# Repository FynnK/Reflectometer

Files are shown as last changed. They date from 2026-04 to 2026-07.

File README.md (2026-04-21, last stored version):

---
tags:
  - electronics
  - hardware-design
  - water-sensor
  - obsidian-skills
status: design-complete
---

---
tags:
  - electronics
  - hardware-design
  - water-sensor
status: design-complete
---

# Multi-LED Spectral Water Quality Sensor

> [!info] Project Overview
> A 24-bit isolated sensing system using pulsed 100mA current sources to measure liquid reflection across three wavelengths (Red, Green, Blue).

## System Architecture

```mermaid
graph TD
    %% -- Non-Isolated Side --
    subgraph NonIsolated ["Power and Control (Digital)"]
        USB[MicroUSB Connector]
        ESP32[ESP32-C3 MCU]
        C_IN[10uF CL21A106]
    end

    %% -- Isolation Barrier --
    subgraph Moat ["Isolation Barrier"]
        ISO1[ISO6742 SPI]
        ISO2[ISO6742 Control]
        ISO3[ISO6742 Extra]
        TRACO[TEA 1-0505 DC/DC]
    end

    %% -- Isolated Side --
    subgraph Isolated ["Isolated Analog Island"]
        %% Power Path
        L47[47uH WE Inductor]
        C_BULK[10uF Filtered]
        TPS[TPS60403 Inverter]
        
        %% Control Signals
        PWM[PWM Filter]
        GATE_SEL[BS170 Selector Gates]
        
        %% Signal Chain
        PD[BPW34S Photodiode]
        TIA[TLV172 TIA]
        ADC[ADS131M02]
        
        %% LED Current Path
        LEDS[RGB LED Array]
        SINK[BS170 Regulator]
        RSENSE[10 ohm Sense Resistor]
    end

    %% Cross-Barrier Links
    USB --> C_IN
    C_IN --> ESP32
    C_IN --> TRACO
    ESP32 --> ISO1
    ESP32 --> ISO2
    
    %% Isolated Routing
    TRACO --> L47
    L47 --> C_BULK
    C_BULK --> TPS
    C_BULK --> LEDS
    
    ISO1 --> ADC
    ISO2 --> PWM
    ISO2 --> GATE_SEL
    
    LEDS --> GATE_SEL
    GATE_SEL --> SINK
    SINK --> RSENSE
    RSENSE --> ADC
    
    PD --> TIA
    TIA --> ADC
````

## Hardware Component Logic

### 1. Power & Noise Suppression

- **Isolated DC/DC:** Uses the [[TEA 1-0505]] to break ground loops.
    
- **The Filter:** A Pi-filter using the **47uH Würth Inductor** and **Ferrite Beads** to scrub switching noise.
    
- **Negative Rail:** The **TPS60403** provides a -5V rail for the **TLV172** to allow the TIA to swing to absolute zero.

### 2. The 100mA Pulsed Source

> [!tip] Ratiometric Measurement
> 
> By routing the voltage from the **10 ohm Sense Resistor** back to ADC Channel 2, we calculate the ratio of reflected light to actual LED current. This cancels out power supply ripples.

- **Regulation:** TLV172 + BS170 (Main Sink).
    
- **Switching:** 3x BS170 (Color Selectors).

## Component List & Budget

|**Component**|**Function**|**Cost**|
|---|---|---|
|[[ADS131M02]]|24-bit ADC|€4.41|
|[[ISO6742]] (x3)|Digital Isolation|€7.68|
|[[TLV172]] (x2)|TIA & Current Source|€2.96|
|[[TEA 1-0505]]|Isolated Power|€1.65|

**Total Estimated BOM:** €24.64 ^total-cost

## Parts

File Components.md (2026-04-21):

| **Category** | **Description** | **Component** | **Value** | **KiCAD Footprint** | **Digikey** | **Price/pcs** |
| --- | --- | --- | --- | --- | --- | --- |
| **Passive** | Capacitor 0805 | CC0805JRNPO9BN470 | 47pF 16V | C0805_2012Metric_Pad1.18x1.45mm_HandSolder  | 311-1107-2-ND | 0,08 € |
| **Passive** | Capacitor 0805 | C0805C103K5RACTU | 10nF 16V | C0805_2012Metric_Pad1.18x1.45mm_HandSolder  | 399-C0805C103K5RACTUTR-ND | 0,07 € |
| **Passive** | Capacitor 0805 | C0805C104K5RACTU | 100nF 16V | C0805_2012Metric_Pad1.18x1.45mm_HandSolder  | 399-C0805C104K5RACTUTR-ND | 0,01 € |
| **Passive** | Capacitor 0805 | C0805C224K5RACTU | 220nF 16V | C0805_2012Metric_Pad1.18x1.45mm_HandSolder  | 399-C0805C224K5RACTUTR-ND | 0,07 € |
| **Passive** | Capacitor 0805 | CL21B105KAFNNNG | 1uF 16V | C0805_2012Metric_Pad1.18x1.45mm_HandSolder  | 1276-6469-2-ND | 0,08 € |
| **Passive** | Capacitor 0805 | CL21A106KOQNNNE | 10uF 16V | C0805_2012Metric_Pad1.18x1.45mm_HandSolder  | 1276-1096-2-ND | 0,08 € |
| **Passive** | Capacitor Electrolyte | 865080343009 | 100uF | CP_Elec_6.3x5.7 | 732-8419 | 0,28 € |
| **Passive** | Resistor 0805 | - | 1Ohm-10Meg | R0805_2012MetricPad1.20x1.40mm_HandSolder | x- | - € |
| **Passive** | Inductor | WE 7447462022 | 2.2uH | L_Radial_D7.0mm_P3.00mm | 732-2566-ND | 0,87 € |
| **Passive** | Inductor | WE 7447462047 | 4.7uH | L_Radial_D7.0mm_P3.00mm | 732-2568-ND | 0,87 € |
| **Passive** | Inductor | WE 744732470 | 47uH | L_Radial_D9.5mm_P5.00mm_Fastron | 732-3748-ND | 1,27 € |
| **Passive** | Inductor / Ferrite | BLM18AG601SN1D | - | L_0603_1608Metric_Pad1.05x0.95mm_HandSolder | 490-1014 | 0,10 € |
| **Connectors** | Stiftleiste 2,54mm | Pinzahl beliebig | Conn_01x10Pin etc. | PinHeader_1x10_P2.54_Vertical etc. | 732-5334-ND | - |
| **Connectors** | Sockelleiste 2,54mm | 801-87-050-10-001101 | Conn_01x10Pin etc. | PinHeader_1x10_P2.54_Vertical etc. | 1212-1218-ND | - |
| **Connectors** | Jumper 2,54mm | QPC02SXGN-RC | - | PinHeader_1x2_P2.54_Vertical | S9337-ND | - |
| **Connectors** | MicroUSB Connector | Amphenol 10103594 | - | KiCADComponent | 609-4050 | 0,80 € |
| **Connectors** | 4*AA Battery Holder | Keystone 2478 | 2 Pins | - | 36-2478-ND | 1,94 € |
| **Active** | Instrumentation Amp | INA128 SOIC8 | - | KiCADComponent | 296-26057 | 9,28 € |
| **Active** | Operational Amp | TLV172 SOIC8 | - | KiCADComponent | 296-47279 | 1,48 € |
| **Active** | Operational Amp | LM321 SOT23-5 | - | KiCADComponent | LM321SN3T1GOSTR-ND | 0,10 € |
| **Active** | NPN Transistor | BC547C TO-92 | - | KiCADComponent | 4878-BC547CCT-ND | 0,14 € |
| **Active** | PNP Transistor | BC557C TO-92 | - | KiCADComponent | 4878-BC557 | 0,14 € |
| **Active** | N-CH MOSFET | BS170 SOT-23-3 | - | KiCADComponent | 4518-BS170FTATR-ND | 0,25 € |
| **Active** | P-CH MOSFET | BSS84 SOT-23-3 | - | KiCADComponent | BSS84TR-ND | 0,34 € |
| **Active** | LED blue | 150120BS75000 | - | LED_1206_3216Metric_HandSolder | 32-4989-2-ND | 0,23 € |
| **Active** | LED green | 150120GS75000 | - | LED_1206_3216Metric_HandSolder | 732-4990-2-ND | 0,23 € |
| **Active** | LED superred | 150120SS75000 | - | LED_1206_3216Metric_HandSolder | 732-4992-2-ND | 0,23 € |
| **Active** | Photodiode | Vishay BPW34S SMD | - | KiCADComponent | 475-BPW34S-ZTR-ND | 1,09 € |
| **Active** | Analog Multiplexer | ADG734 | - | KiCADComponent | ADG734BRUZ-REELTR-ND | 4,70 € |
| **Active** | USB Interface | MCP2221AT-I/SL | SOIC14 | KiCADComponent | 150-MCP2221AT-I/SLTR-ND | 2,53 € |
| **Active** | Digital Isolator | ISO6742 | SOIC16 | KiCADComponent | 296-ISO6742FDWRTR-ND | 2,56 € |
| **Active** | DCDC Converter | TEA 1-0505 | - | KiCADComponent | 951-TEA1-0505-ND | 1,65 € |
| **Active** | LDO positive | LM317_SOT-223 | configurable | KiCADComponent | 296-12602-2-ND | 0,63 € |
| **Active** | LDO negative | LM337_TO252 | configurable | KiCADComponent | 296-21578-2-ND | 1,00 € |
| **Active** | Voltage Inverter | TPS60403QDBVRQ1 | Charge Pump | KiCADComponent | 296-18036-2-ND | 1,16 € |
| **Active** | ADC 24 Bit | ADS131M02 | ADS131M04 | Schematic and Layout | 296-ADS131M02 | 4,41 € |

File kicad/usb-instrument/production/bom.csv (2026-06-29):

Designator | Footprint | Quantity | Value | LCSC Part #
C1, C19, C2 | 0805 | 3 | 10n
C10, C13, C17, C18, C4, C9 | 0805 | 6 | 100n
C11, C14, C16, C21 | 0805 | 4 | 10u
C12, C20, C25 | 0805 | 3 | 220n
C15 | CP_Elec_6.3x5.7 | 1 | 100u
C22, C23, C24, C5 | 0805 | 4 | 1u
C3 | 0805 | 1 | 47p (optional)
D4 | Osram_BPW34S-SMD | 1 | BPW34-SMD
D5, D6, D7 | 1206 | 3 | LED
FB1 | 0603 | 1 | FerriteBead
J1 | USB_Micro-B_Amphenol_10103594-0001LF_Horizontal | 1 | USB_B_Micro
J2 | USB_C_Receptacle_G-Switch_GT-USB-7010ASV | 1 | USB_C_Receptacle_USB2.0_14P
Q5, Q7, Q8 | SOT-23-3 | 3 | BS170
Q6 | SOT-23 | 1 | BSS84
R1, R2, R28, R3, R4 | 0805 | 5 | 1k
R11, R12, R26, R27, R8 | 0805 | 5 | 10k
R13 | 0805 | 1 | 18k
R14 | 0805 | 1 | 220
R15 | 0805 | 1 | 360
R18, R19 | 0805 | 2 | 4.7k
R29, R30, R34, R36 | 0805 | 4 | 100
R31, R35, R37 | 0805 | 3 | 47k
R32 | 0805 | 1 | 33
R33 | 0805 | 1 | 1
R5, R6 | 0805 | 2 | 5k1
R7 | 0805 | 1 | 22
TP1 | TestPoint_Pad_D2.5mm | 1 | MCP_RX
TP17 | TestPoint_Pad_D2.5mm | 1 | TestPoint
TP2 | TestPoint_Pad_D2.5mm | 1 | MCP_TX
U1 | XIAO-ESP32-C3-DIP-SMD | 1 | XIAO-ESP32-C3-DIP
U12, U13 | SOT-23-5 | 2 | LM321
U3 | SOT-223-3_TabPin2 | 1 | LM317_SOT-223
U4 | SOIC-16W_7.5x10.3mm_P1.27mm | 1 | ISO6742
U5 | SOIC-14_3.9x8.7mm_P1.27mm | 1 | MCP2221AxSL
U6 | TSSOP20_PW_TEX | 1 | ADS131M02IPWR
U8 | Converter_DCDC_TRACO_TEA1-xxxx_THT | 1 | TEA 1-0505
U9 | SOIC-8-1EP_3.9x4.9mm_P1.27mm_EP2.514x3.2mm | 1 | TLV172IDCK
Y1 | Crystal_SMD_7050-4Pin_7.0x5.0mm | 1 | XO32

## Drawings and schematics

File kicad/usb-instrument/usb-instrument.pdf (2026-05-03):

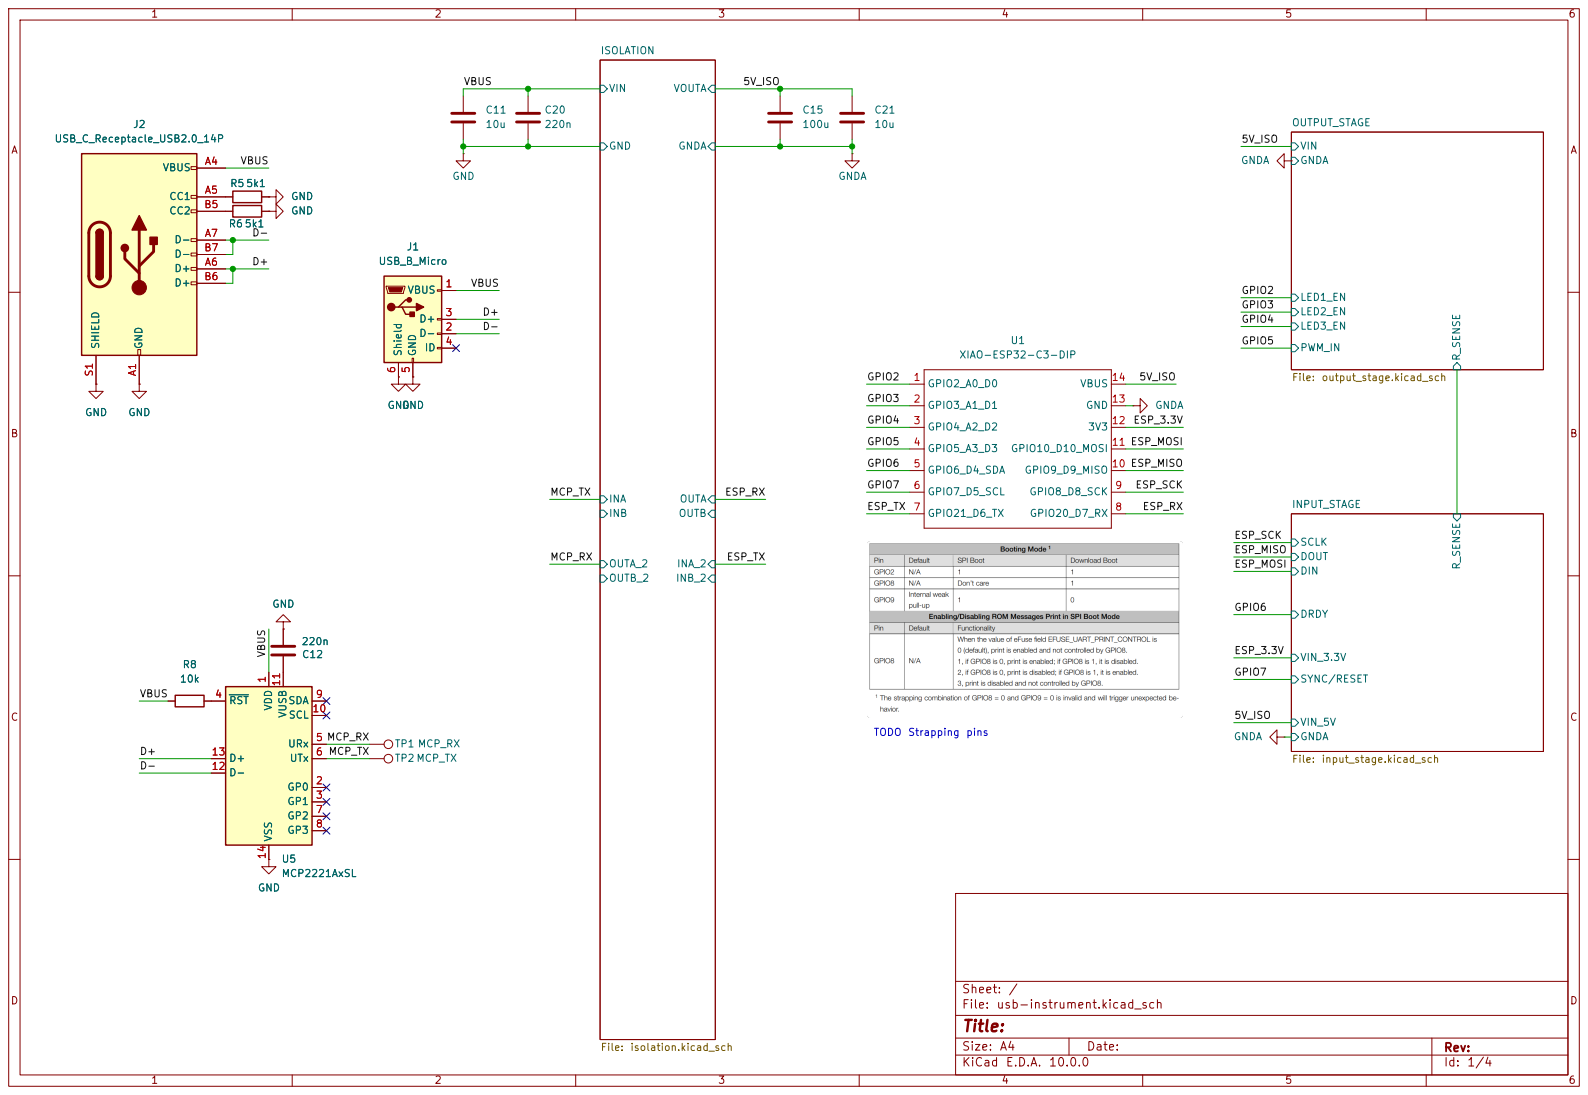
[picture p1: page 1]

TODO Strapping pins GND

Size: A4 | Rev:
KiCad E.D.A. 10.0.0 | Id: 1/4

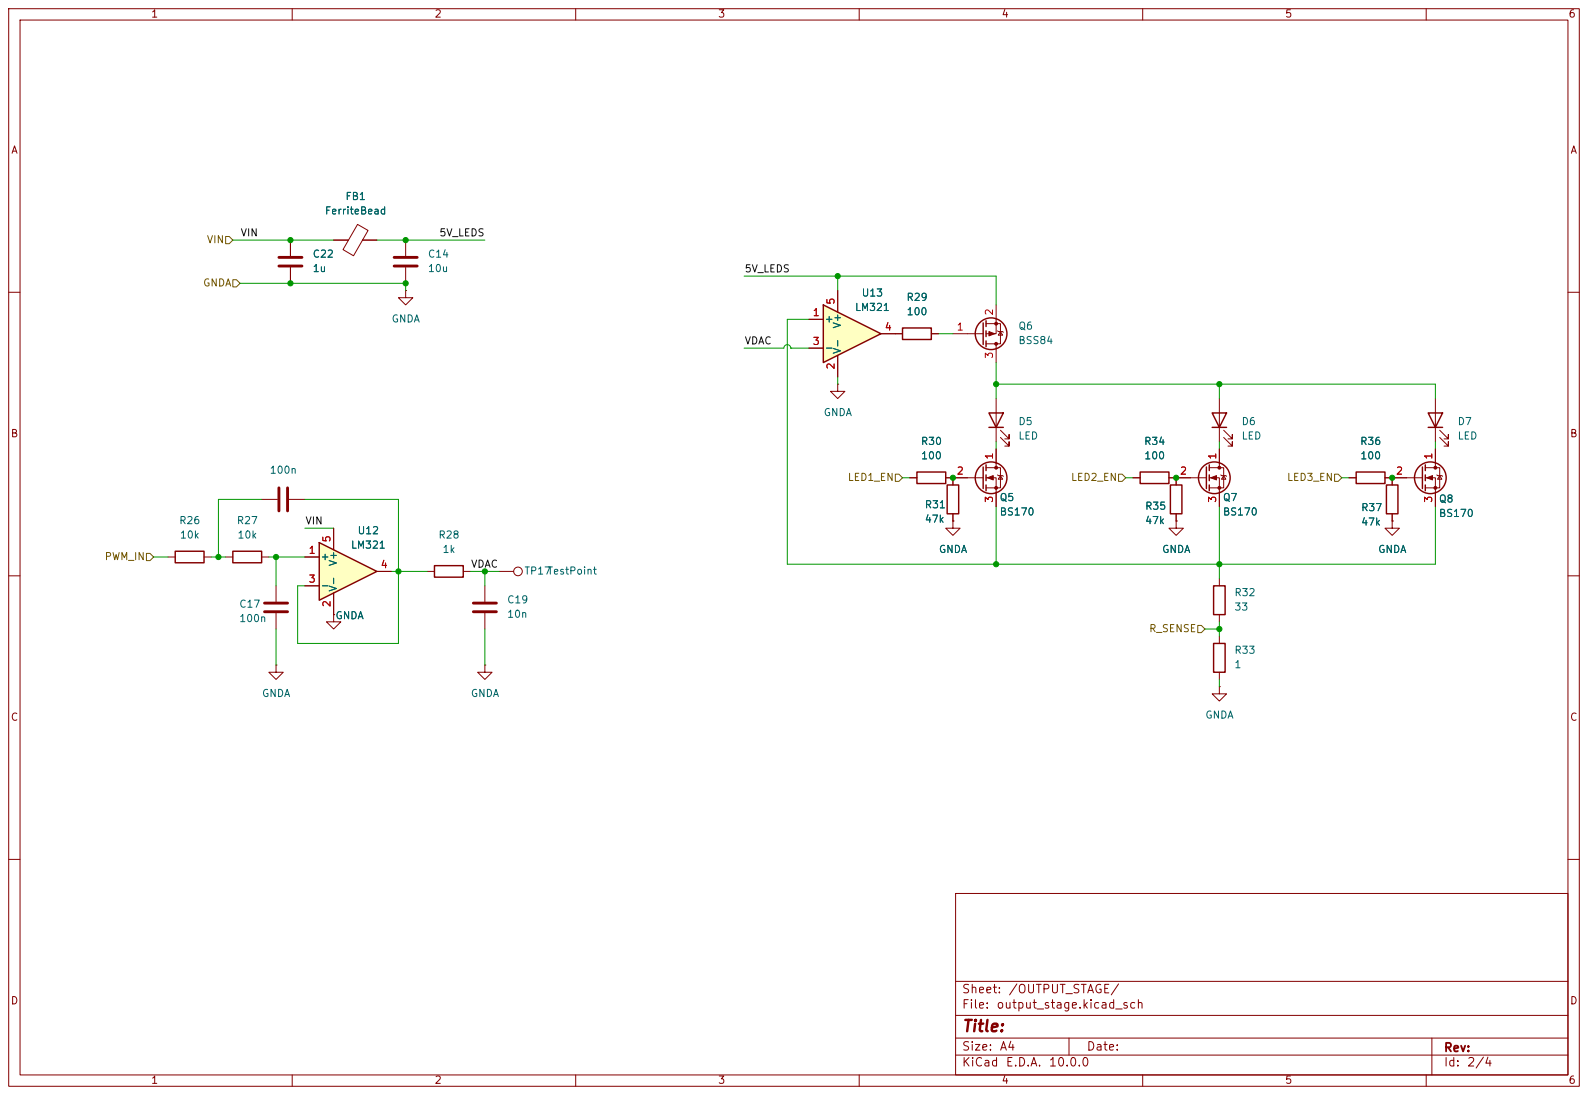
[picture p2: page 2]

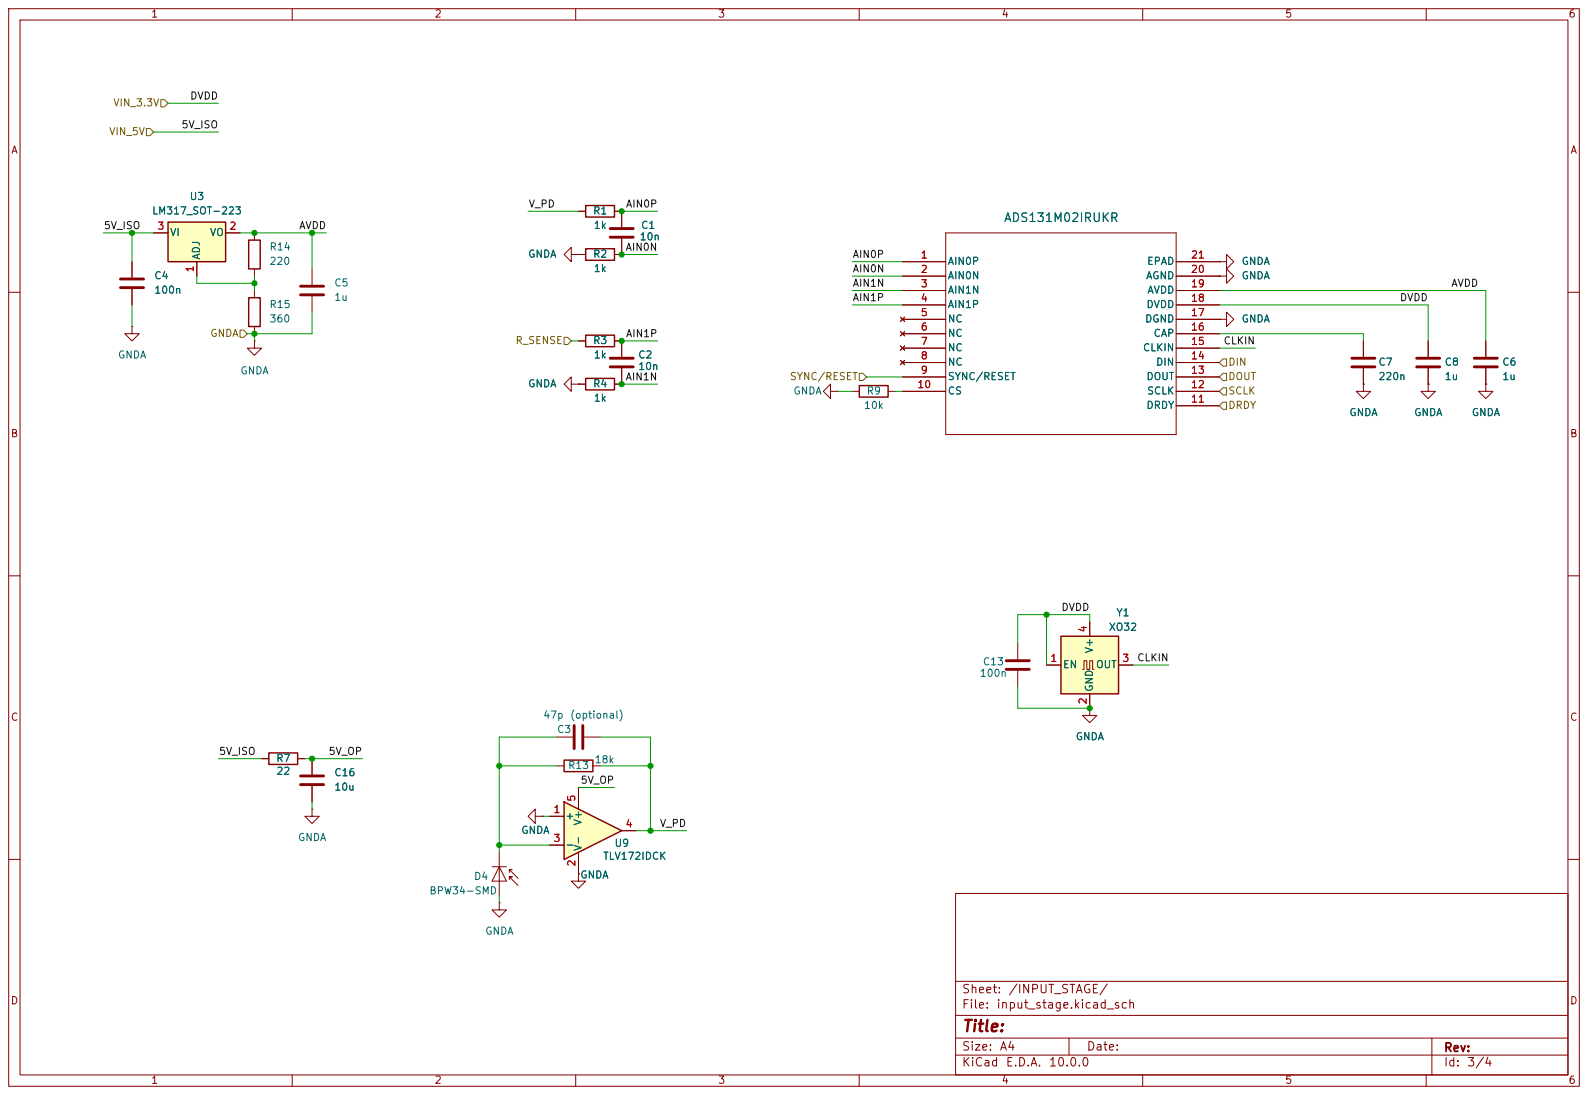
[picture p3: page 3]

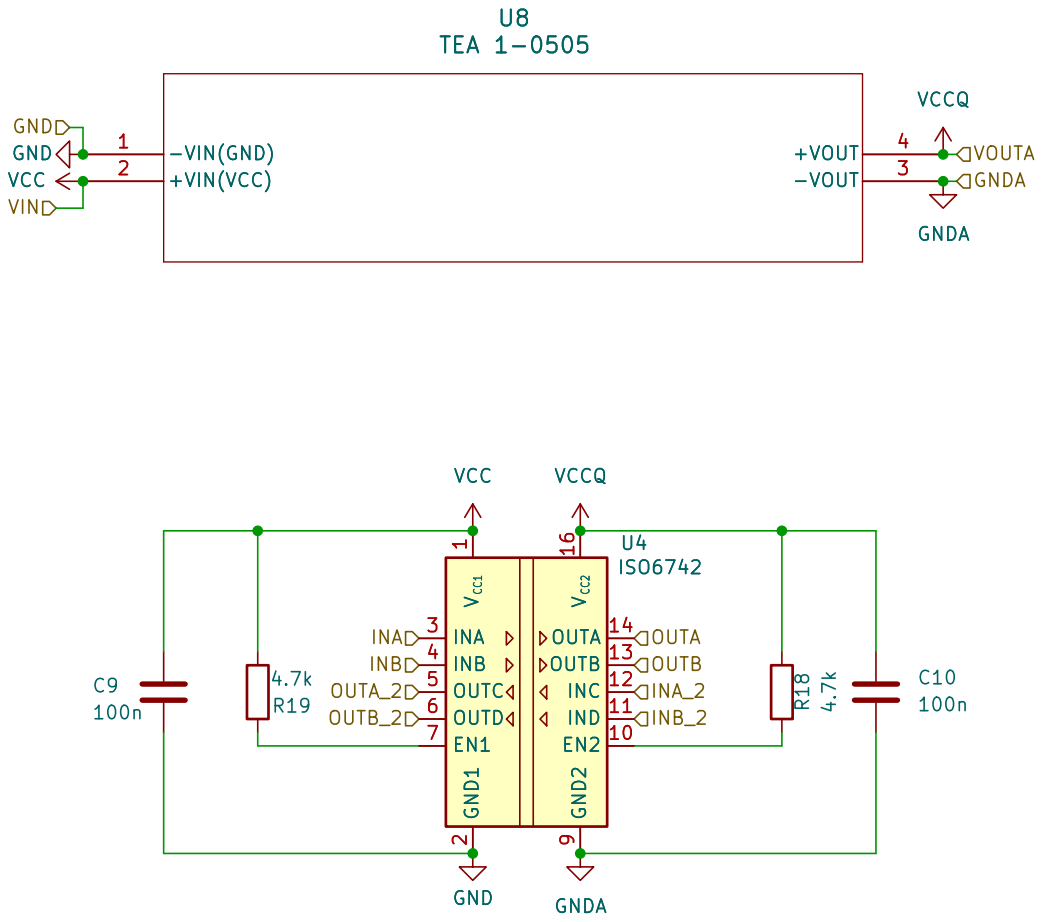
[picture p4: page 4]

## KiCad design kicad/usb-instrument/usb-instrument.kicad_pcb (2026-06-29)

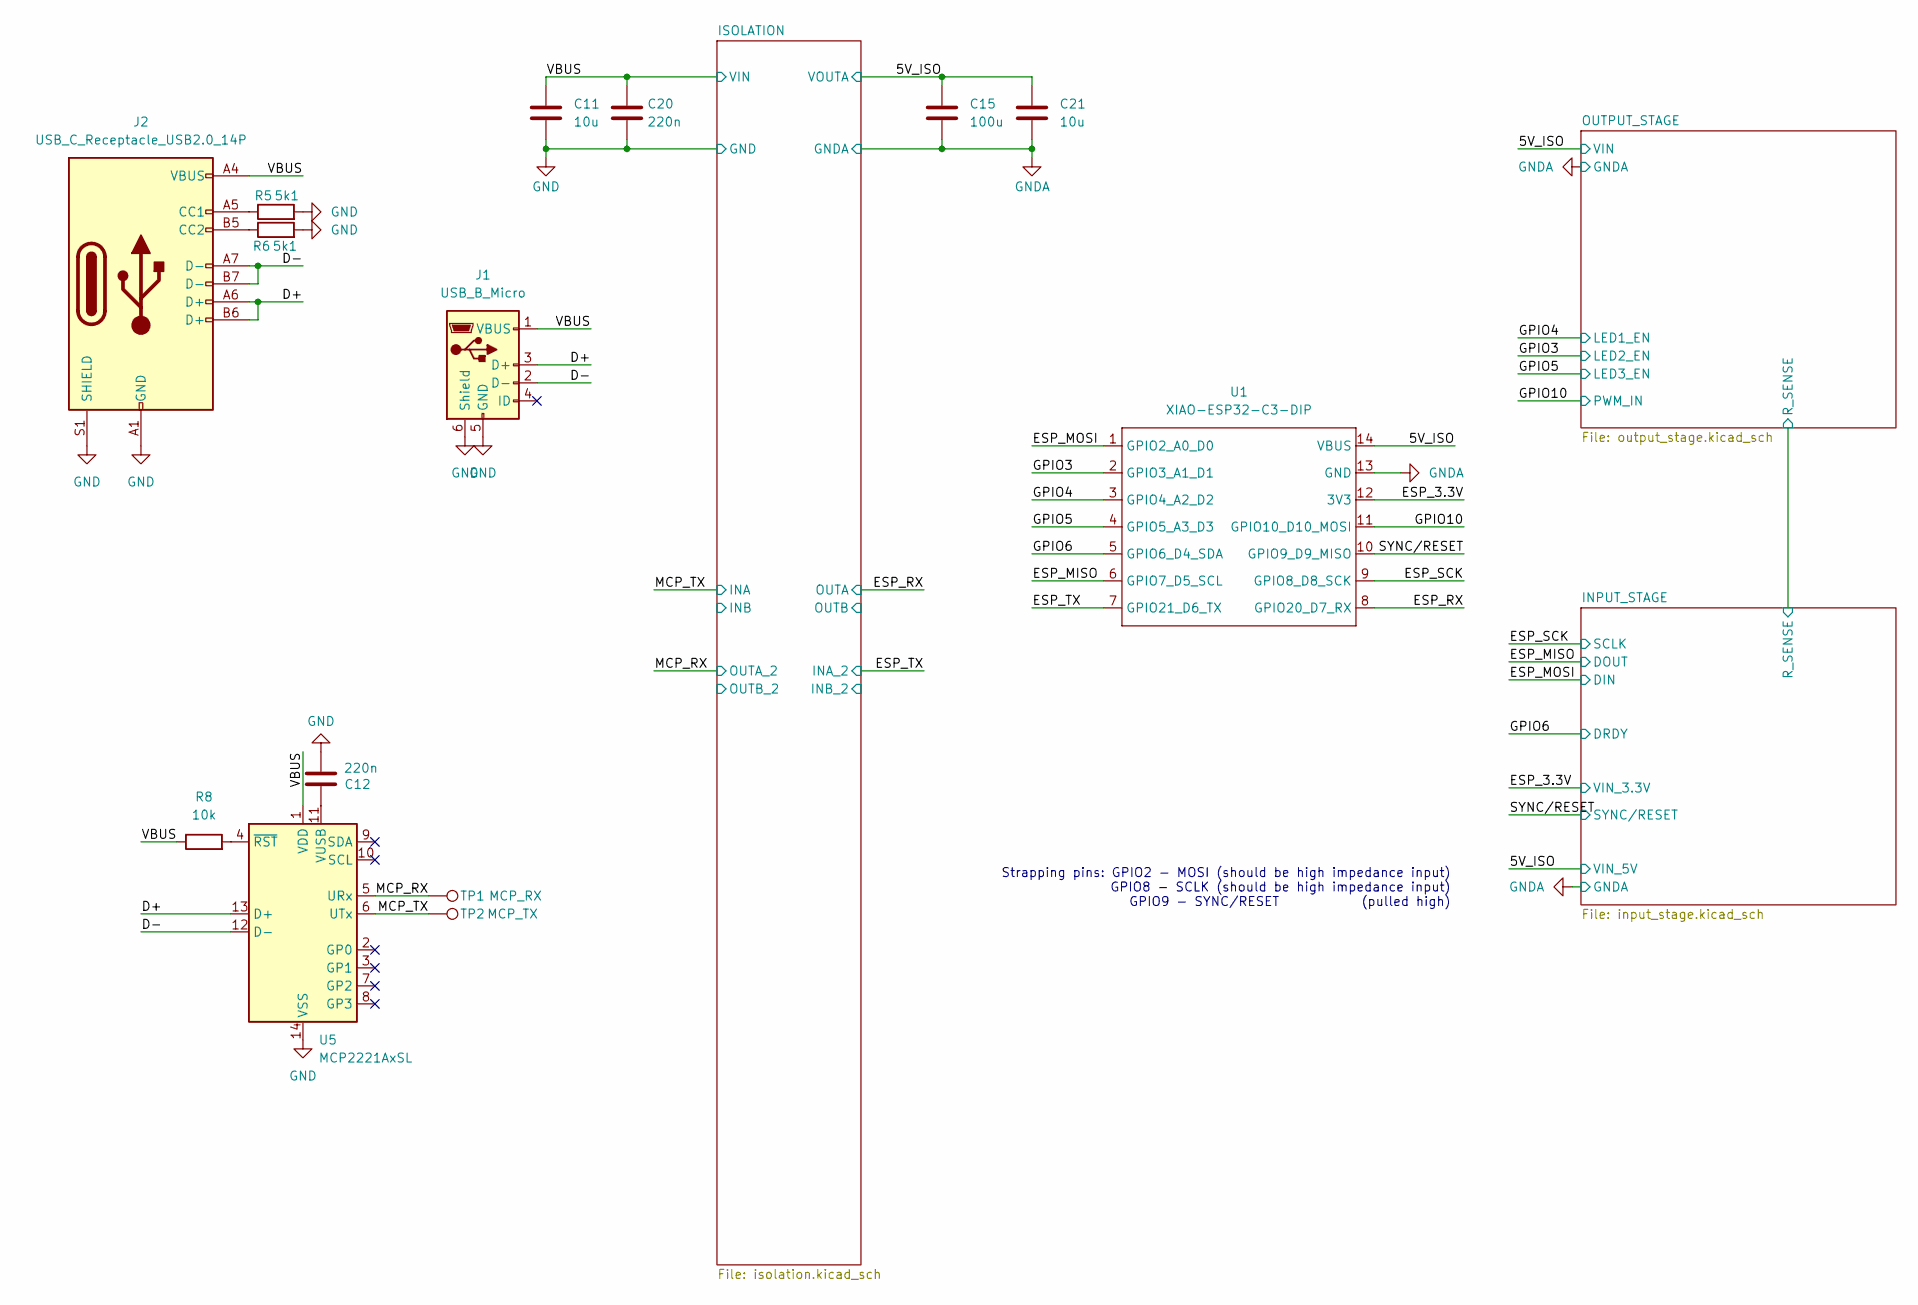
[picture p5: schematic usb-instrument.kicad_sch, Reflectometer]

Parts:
C11, C21: 10u; C_0805_2012Metric_Pad1.18x1.45mm_HandSolder
C12, C20: 220n; C_0805_2012Metric_Pad1.18x1.45mm_HandSolder
C15: 100u; CP_Elec_6.3x5.7
J1: USB_B_Micro; USB_Micro-B_Amphenol_10103594-0001LF_Horizontal
J2: USB_C_Receptacle_USB2.0_14P; USB_C_Receptacle_G-Switch_GT-USB-7010ASV
R5, R6: 5k1; R_0805_2012Metric_Pad1.20x1.40mm_HandSolder
R8: 10k; R_0805_2012Metric_Pad1.20x1.40mm_HandSolder
TP1: MCP_RX; TestPoint_Pad_D2.5mm
TP2: MCP_TX; TestPoint_Pad_D2.5mm
U1: XIAO-ESP32-C3-DIP; XIAO-ESP32-C3-DIP-SMD
U5: MCP2221AxSL; SOIC-14_3.9x8.7mm_P1.27mm

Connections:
/D+: J1.3 (D+), J2.A6 (D+), J2.B6 (D+), U5.13 (D+)
/D-: J1.2 (D-), J2.A7 (D-), J2.B7 (D-), U5.12 (D-)
/ESP_3.3V: U1.12 (3V3); also elsewhere on the board
/ESP_MISO: U1.6 (GPIO7_D5_SCL); also elsewhere on the board
/ESP_MOSI: U1.1 (GPIO2_A0_D0); also elsewhere on the board
/ESP_RX: U1.8 (GPIO20_D7_RX); also elsewhere on the board
/ESP_SCK: U1.9 (GPIO8_D8_SCK); also elsewhere on the board
/ESP_TX: U1.7 (GPIO21_D6_TX); also elsewhere on the board
/GPIO3: U1.2 (GPIO3_A1_D1); also elsewhere on the board
/GPIO4: U1.3 (GPIO4_A2_D2); also elsewhere on the board
/GPIO5: U1.4 (GPIO5_A3_D3); also elsewhere on the board
/GPIO6: U1.5 (GPIO6_D4_SDA); also elsewhere on the board
/GPIO10: U1.11 (GPIO10_D10_MOSI); also elsewhere on the board
/MCP_RX: TP1.1 (1_1), U5.5 (URx); also elsewhere on the board
/MCP_TX: TP2.1 (1_1), U5.6 (UTx); also elsewhere on the board
/SYNC/RESET: U1.10 (GPIO9_D9_MISO); also elsewhere on the board
GND: C11.2, C12.2, C20.2, J1.5 (GND), J1.6 (Shield), J2.A1 (GND), J2.A12 (GND), J2.B1 (GND), J2.B12 (GND), J2.S1 (SHIELD), R5.2, R6.2, U5.14 (VSS); also elsewhere on the board
GNDA: C15.2, C21.2, U1.13 (GND); also elsewhere on the board
unnamed: J2.A5 (CC1), R5.1
unnamed: J2.B5 (CC2), R6.1
unnamed: C12.1, U5.11 (VUSB)
unnamed: R8.2, U5.4 (~RST)
VCC: C11.1, C20.1, J1.1 (VBUS), J2.A4 (VBUS), J2.A9 (VBUS), J2.B4 (VBUS), J2.B9 (VBUS), R8.1, U5.1 (VDD); also elsewhere on the board
VCCQ: C15.1, C21.1, U1.14 (VBUS); also elsewhere on the board

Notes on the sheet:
Strapping pins: GPIO2 - MOSI (should be high impedance input) GPIO8 - SCLK (should be high impedance input) GPIO9 - SYNC/RESET (pulled high)

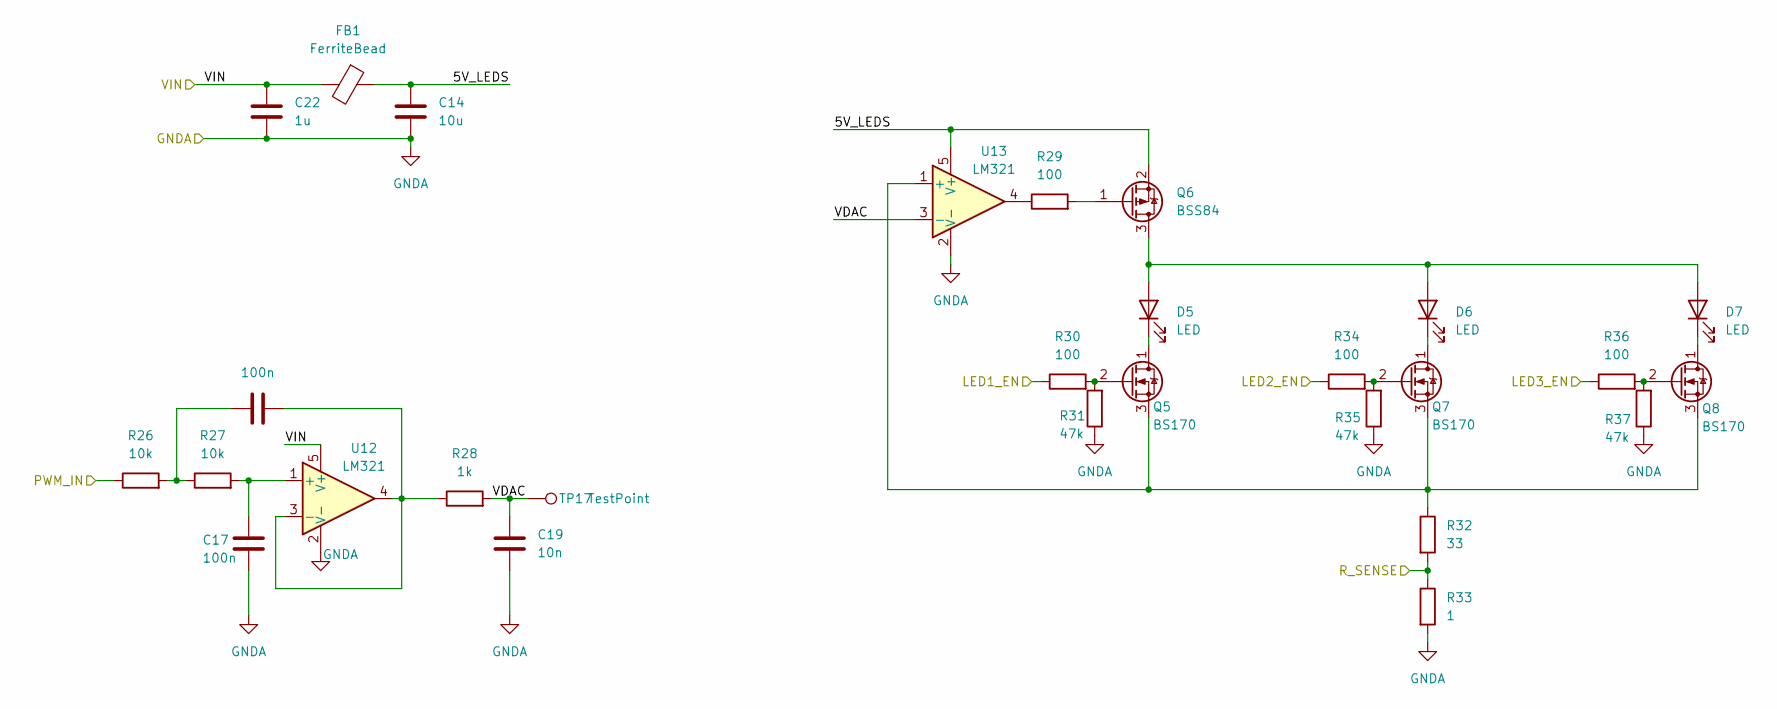
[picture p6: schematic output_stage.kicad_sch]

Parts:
C14: 10u; C_0805_2012Metric_Pad1.18x1.45mm_HandSolder
C17, C18: 100n; C_0805_2012Metric_Pad1.18x1.45mm_HandSolder
C19: 10n; C_0805_2012Metric_Pad1.18x1.45mm_HandSolder
C22: 1u; C_0805_2012Metric_Pad1.18x1.45mm_HandSolder
D5, D6, D7: LED; LED_1206_3216Metric
FB1: FerriteBead; L_0603_1608Metric_Pad1.05x0.95mm_HandSolder
Q5, Q7, Q8: BS170; SOT-23-3
Q6: BSS84; SOT-23
R26, R27: 10k; R_0805_2012Metric_Pad1.20x1.40mm_HandSolder
R28: 1k; R_0805_2012Metric_Pad1.20x1.40mm_HandSolder
R29, R30, R34, R36: 100; R_0805_2012Metric_Pad1.20x1.40mm_HandSolder
R31, R35, R37: 47k; R_0805_2012Metric_Pad1.20x1.40mm_HandSolder
R32: 33; R_0805_2012Metric_Pad1.20x1.40mm_HandSolder
R33: 1; R_0805_2012Metric_Pad1.20x1.40mm_HandSolder
TP17: TestPoint; TestPoint_Pad_D2.5mm
U12, U13: LM321; SOT-23-5

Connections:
/GPIO3: R34.1; also elsewhere on the board
/GPIO4: R30.1; also elsewhere on the board
/GPIO5: R36.1; also elsewhere on the board
/GPIO10: R26.1; also elsewhere on the board
/INPUT_STAGE/R_SENSE: R32.2, R33.1; also elsewhere on the board
/OUTPUT_STAGE/5V_LEDS: C14.1, FB1.1, Q6.2 (S), U13.5 (V+)
/OUTPUT_STAGE/VDAC: C19.1, R28.2, TP17.1 (1_1), U13.3 (-)
GNDA: C14.2, C17.1, C19.2, C22.2, R31.1, R33.2, R35.1, R37.1, U12.2 (V-), U13.2 (V-); also elsewhere on the board
unnamed: C18.1, R26.2, R27.1
unnamed: D5.2 (A), D6.2 (A), D7.2 (A), Q6.3 (D)
unnamed: D5.1 (K), Q5.1 (D)
unnamed: D6.1 (K), Q7.1 (D)
unnamed: D7.1 (K), Q8.1 (D)
unnamed: Q5.2 (G), R30.2, R31.2
unnamed: Q5.3 (S), Q7.3 (S), Q8.3 (S), R32.1, U13.1 (+)
unnamed: Q6.1 (G), R29.2
unnamed: Q7.2 (G), R34.2, R35.2
unnamed: Q8.2 (G), R36.2, R37.2
unnamed: R29.1, U13.4
unnamed: C17.2, R27.2, U12.1 (+)
unnamed: C18.2, R28.1, U12.3 (-), U12.4
VCCQ: C22.1, FB1.2, U12.5 (V+); also elsewhere on the board

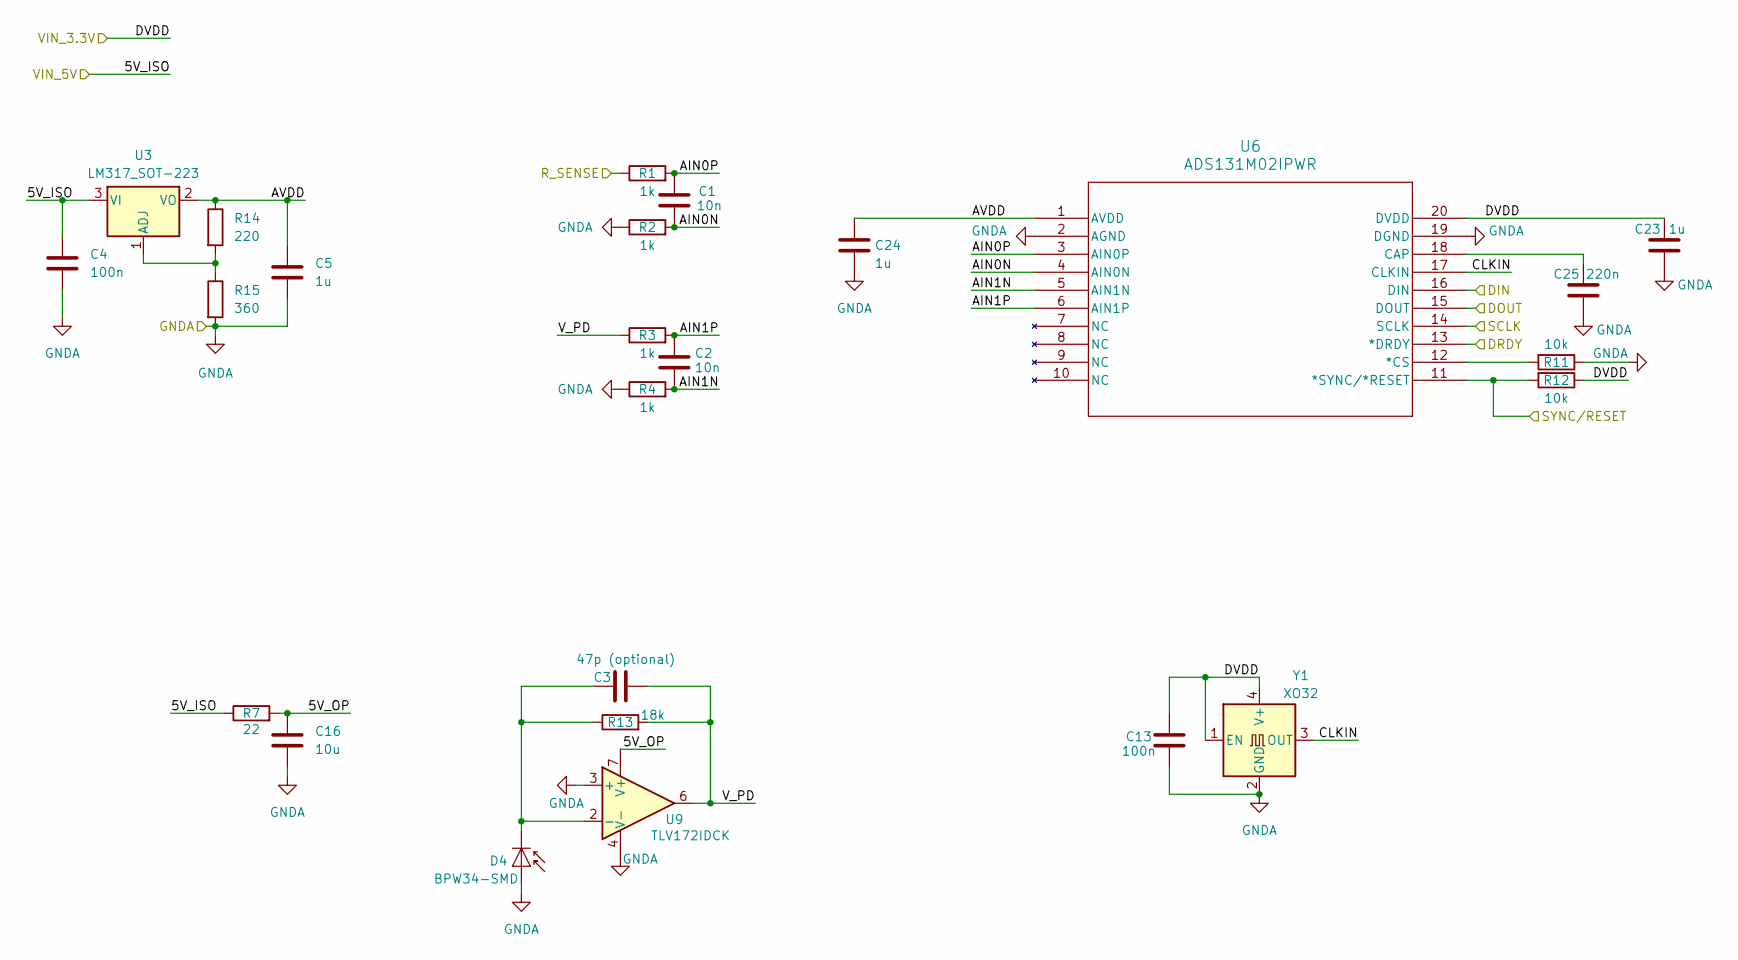
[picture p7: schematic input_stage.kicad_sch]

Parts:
C1, C2: 10n; C_0805_2012Metric_Pad1.18x1.45mm_HandSolder
C3: 47p (optional); C_0805_2012Metric_Pad1.18x1.45mm_HandSolder
C4, C13: 100n; C_0805_2012Metric_Pad1.18x1.45mm_HandSolder
C5, C23, C24: 1u; C_0805_2012Metric_Pad1.18x1.45mm_HandSolder
C16: 10u; C_0805_2012Metric_Pad1.18x1.45mm_HandSolder
C25: 220n; C_0805_2012Metric_Pad1.18x1.45mm_HandSolder
D4: BPW34-SMD; Osram_BPW34S-SMD
R1, R2, R3, R4: 1k; R_0805_2012Metric_Pad1.20x1.40mm_HandSolder
R7: 22; R_0805_2012Metric_Pad1.20x1.40mm_HandSolder
R11, R12: 10k; R_0805_2012Metric_Pad1.20x1.40mm_HandSolder
R13: 18k; R_0805_2012Metric_Pad1.20x1.40mm_HandSolder
R14: 220; R_0805_2012Metric_Pad1.20x1.40mm_HandSolder
R15: 360; R_0805_2012Metric_Pad1.20x1.40mm_HandSolder
U3: LM317_SOT-223; SOT-223-3_TabPin2
U6: ADS131M02IPWR; TSSOP20_PW_TEX
U9: TLV172IDCK; SOIC-8-1EP_3.9x4.9mm_P1.27mm_EP2.514x3.2mm
Y1: XO32; Crystal_SMD_7050-4Pin_7.0x5.0mm

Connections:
/ESP_3.3V: C13.1, C23.1, R12.1, U6.20 (DVDD), Y1.1 (EN), Y1.4 (V+); also elsewhere on the board
/ESP_MISO: U6.15 (DOUT); also elsewhere on the board
/ESP_MOSI: U6.16 (DIN); also elsewhere on the board
/ESP_SCK: U6.14 (SCLK); also elsewhere on the board
/GPIO6: U6.13 (*DRDY); also elsewhere on the board
/INPUT_STAGE/5V_OP: C16.1, R7.2, U9.7 (V+)
/INPUT_STAGE/AIN0N: C1.2, R2.2, U6.4 (AIN0N)
/INPUT_STAGE/AIN0P: C1.1, R1.2, U6.3 (AIN0P)
/INPUT_STAGE/AIN1N: C2.2, R4.2, U6.5 (AIN1N)
/INPUT_STAGE/AIN1P: C2.1, R3.2, U6.6 (AIN1P)
/INPUT_STAGE/AVDD: C5.1, C24.1, R14.1, U3.2 (VO), U6.1 (AVDD)
/INPUT_STAGE/CLKIN: U6.17 (CLKIN), Y1.3 (OUT)
/INPUT_STAGE/R_SENSE: R1.1; also elsewhere on the board
/INPUT_STAGE/V_PD: C3.2, R3.1, R13.2, U9.6
/SYNC/RESET: R12.2, U6.11 (*SYNC/*RESET); also elsewhere on the board
GNDA: C4.2, C5.2, C13.2, C16.2, C23.2, C24.2, C25.2, D4.2 (A), R2.1, R4.1, R11.1, R15.2, U6.2 (AGND), U6.19 (DGND), U9.3 (+), U9.4 (V-), Y1.2 (GND); also elsewhere on the board
unnamed: C3.1, D4.1 (K), R13.1, U9.2 (-)
unnamed: R14.2, R15.1, U3.1 (ADJ)
unnamed: R11.2, U6.12 (*CS)
unnamed: C25.1, U6.18 (CAP)
VCCQ: C4.1, R7.1, U3.3 (VI); also elsewhere on the board

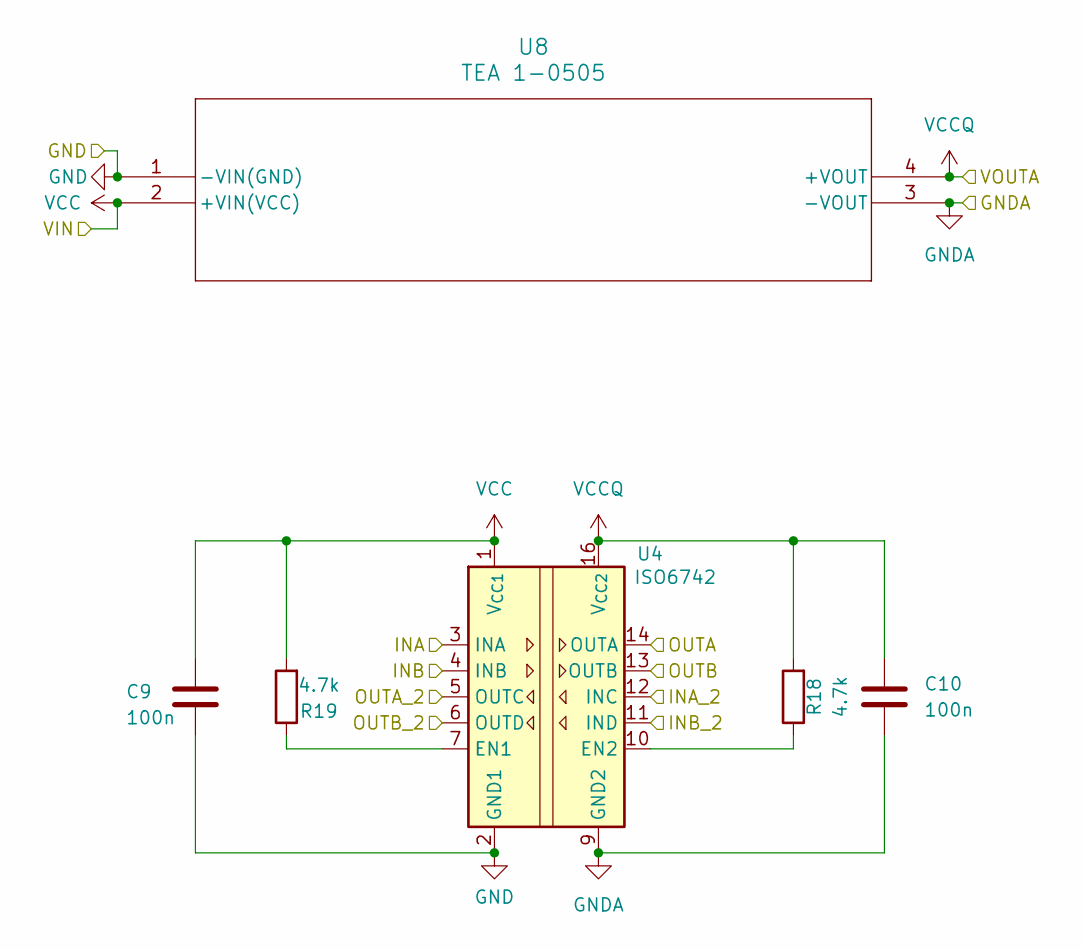
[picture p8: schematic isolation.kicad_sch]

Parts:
C9, C10: 100n; C_0805_2012Metric_Pad1.18x1.45mm_HandSolder
R18, R19: 4.7k; R_0805_2012Metric_Pad1.20x1.40mm_HandSolder
U4: ISO6742; SOIC-16W_7.5x10.3mm_P1.27mm
U8: TEA 1-0505; Converter_DCDC_TRACO_TEA1-xxxx_THT

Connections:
/ESP_RX: U4.14 (OUTA); also elsewhere on the board
/ESP_TX: U4.12 (INC); also elsewhere on the board
/ISOLATION/INB: U4.4 (INB)
/ISOLATION/INB_2: U4.11 (IND)
/ISOLATION/OUTB: U4.13 (OUTB)
/ISOLATION/OUTB_2: U4.6 (OUTD)
/MCP_RX: U4.5 (OUTC); also elsewhere on the board
/MCP_TX: U4.3 (INA); also elsewhere on the board
GND: C9.2, U4.2 (GND1), U4.8 (GND1), U8.1 (-VIN(GND)); also elsewhere on the board
GNDA: C10.2, U4.9 (GND2), U4.15 (GND2), U8.3 (-VOUT); also elsewhere on the board
unnamed: R19.1, U4.7 (EN1)
unnamed: R18.1, U4.10 (EN2)
VCC: C9.1, R19.2, U4.1 (V_{CC1}), U8.2 (+VIN(VCC)); also elsewhere on the board
VCCQ: C10.1, R18.2, U4.16 (V_{CC2}), U8.4 (+VOUT); also elsewhere on the board

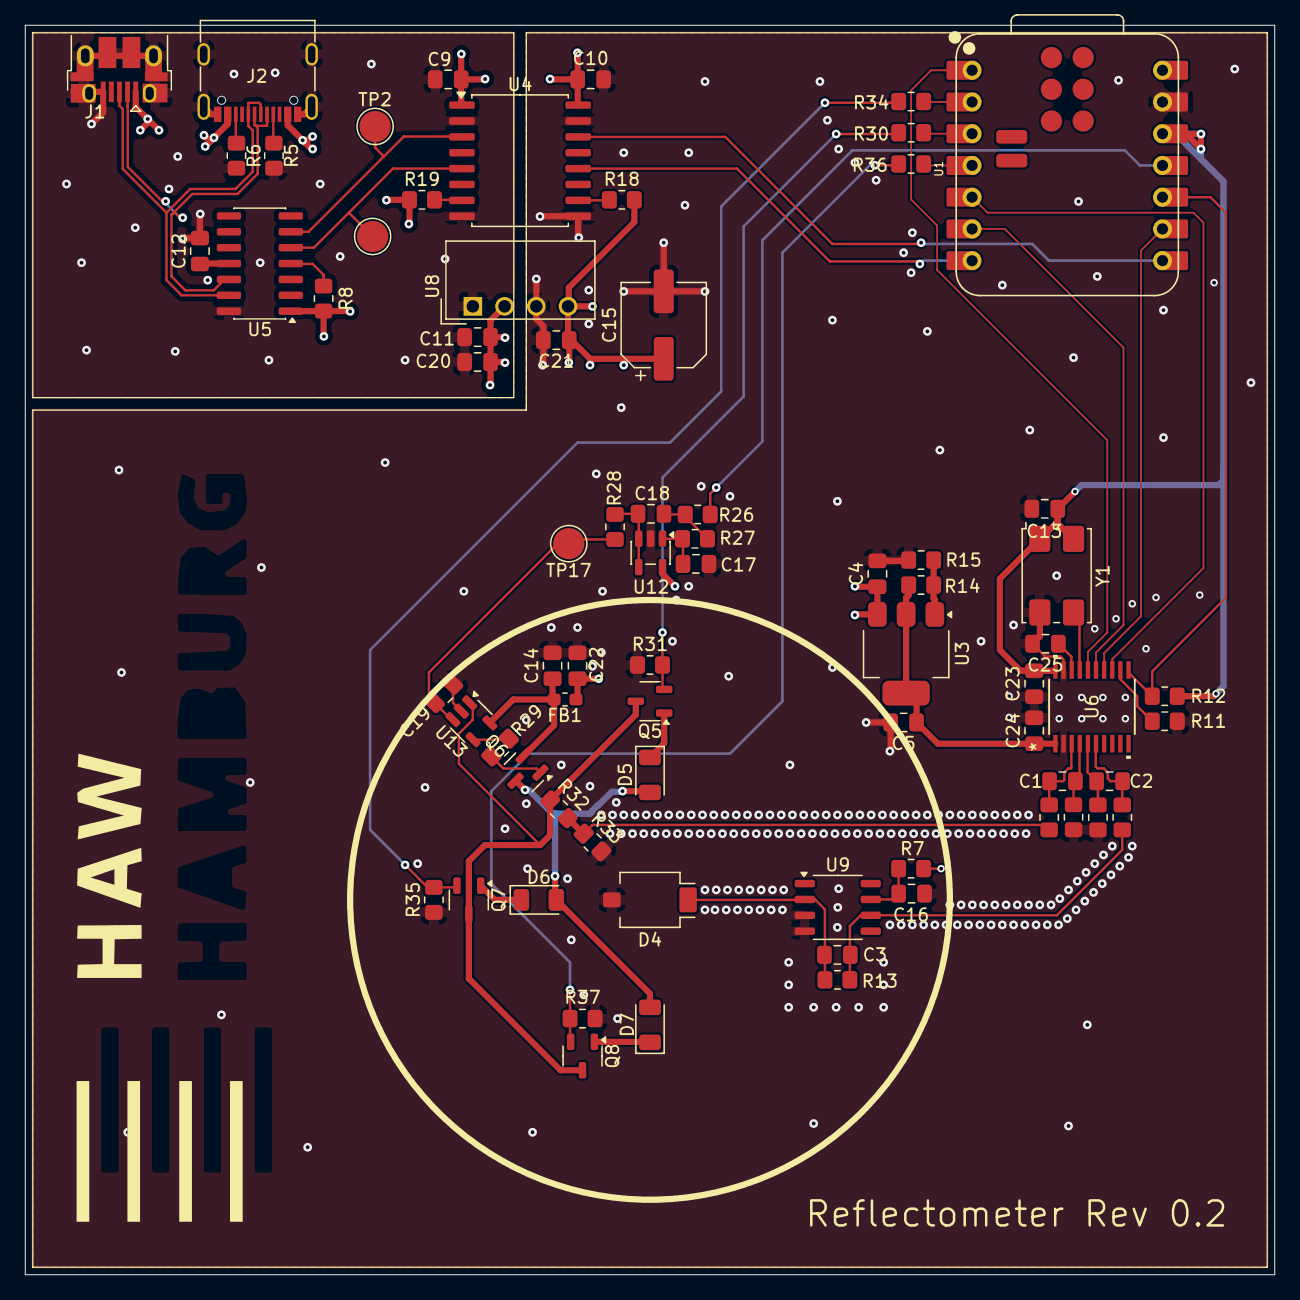
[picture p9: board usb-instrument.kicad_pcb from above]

Board: 4 copper layers, 100.0 x 100.0 mm, 73 parts (0 on the bottom side), 54 nets.

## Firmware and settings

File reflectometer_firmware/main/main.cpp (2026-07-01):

#include <cstdint>
#include <stdio.h>
#include "sdkconfig.h"
#include "freertos/FreeRTOS.h"
#include "freertos/task.h"
#include "esp_err.h"

#include "Ads131m02.hpp"
#include "LedControl.hpp"
#include "ClockGenerator.hpp"
#include "SerialControl.hpp"

const double ADC_FULL_SCALE = 8388608.0;
const double ADC_VREF = 1.2;
const double R_SENSE = 10.0;

Ads131m02 adc;
LedControl leds;
SerialControl serial;

extern "C" void app_main(void) {
    // 1. Initialize Hardware Components
    generate_adc_mclk();

    adc.init_pins();
    vTaskDelay(pdMS_TO_TICKS(100));
    adc.init_spi();

    // 2. Configure ADC Registers
    adc.send_software_reset();
    vTaskDelay(pdMS_TO_TICKS(10));
    adc.write_register(Ads131m02::REG_MODE, Ads131m02::MODE_WLENGTH_24);
    adc.write_register(Ads131m02::REG_CLOCK, Ads131m02::CLOCK_CH0_EN | Ads131m02::CLOCK_CH1_EN | Ads131m02::CLOCK_OSR(Ads131m02::OSR_4096) | Ads131m02::CLOCK_PWR_HR);

    leds.begin();
    serial.begin();

    int32_t ch0_offset;
    int32_t ch1_offset;
    uint8_t num_presamples = 80;
    uint8_t num_samples = 160;
    double reflection[3] = {};
    double current[3] = {};

    while (1) {
        serial.process_commands();
        for(int led = 0; led < 3; led++){
            // Resynchronize internal Sinc3 filters cleanly via SPI command
            adc.software_sync();
            for(int i = 0; i < 3; i++){
                adc.sample();
            }

            int64_t sum_ch0 = 0;
            int64_t sum_ch1 = 0;
            for(int i = 0; i < num_presamples; i++){
                sum_ch0 += adc.sample().getCh0();
                sum_ch1 += adc.sample().getCh1();
            }
            ch0_offset = sum_ch0 / num_presamples;
            ch1_offset = sum_ch1 / num_presamples;

            adc.software_sync();
            leds.pulse(led, num_samples + 10, serial.brightness_for_led(led));
            for(int i = 0; i < 3; i++){
                adc.sample();
            }

            sum_ch0 = 0;
            sum_ch1 = 0;
            for(int i = 0; i < num_samples; i++){
                sum_ch0 += adc.sample().getCh0();
                sum_ch1 += adc.sample().getCh1();
            }
            int32_t ch0_res = llabs((sum_ch0 / num_samples) - ch0_offset);
            int32_t ch1_res = llabs((sum_ch1 / num_samples) - ch1_offset);

            reflection[led] = (double)ch1_res / ch0_res;
            current[led] = (ch0_res / ADC_FULL_SCALE) * (ADC_VREF / R_SENSE) * 1000;

            vTaskDelay(10);

            //double led_current = (avg_counts / ADC_FULL_SCALE) * (ADC_VREF / R_SENSE);
            //double ch1_voltage = (ch1_avg_counts / ADC_FULL_SCALE) * ADC_VREF;
        }

        serial.send_data(reflection, current);
    }
}

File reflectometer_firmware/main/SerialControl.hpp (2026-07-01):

#pragma once

#include "driver/uart.h"
#include "driver/gpio.h"
#include "esp_err.h"
#include <cstring>
#include <cstdio>

class SerialControl {
public:
    static constexpr uart_port_t UART_NUM = UART_NUM_0;
    static constexpr int TX_PIN = GPIO_NUM_21;
    static constexpr int RX_PIN = GPIO_NUM_20;
    static constexpr int BUF_SIZE = 256;
    static constexpr uint32_t MAX_BRIGHTNESS = 5500;

    uint8_t led_intensity[3] = {0, 0, 0};

    void begin() {
        uart_config_t cfg = {};
        cfg.baud_rate = 115200;
        cfg.data_bits = UART_DATA_8_BITS;
        cfg.parity = UART_PARITY_DISABLE;
        cfg.stop_bits = UART_STOP_BITS_1;
        cfg.flow_ctrl = UART_HW_FLOWCTRL_DISABLE;
        cfg.source_clk = UART_SCLK_DEFAULT;
        ESP_ERROR_CHECK(uart_param_config(UART_NUM, &cfg));
        ESP_ERROR_CHECK(uart_set_pin(UART_NUM, TX_PIN, RX_PIN, UART_PIN_NO_CHANGE, UART_PIN_NO_CHANGE));
        ESP_ERROR_CHECK(uart_driver_install(UART_NUM, BUF_SIZE, BUF_SIZE, 0, nullptr, 0));
    }

    void send_data(double reflections[3], double currents[3]) {
        char line[128];
        int len = snprintf(line, sizeof(line),
            "RED: %.3f @ %.2fmA BLUE: %.3f @ %.2fmA GREEN: %.3f @ %.2fmA\n",
            reflections[0], currents[0],
            reflections[1], currents[1],
            reflections[2], currents[2]);
        uart_write_bytes(UART_NUM, line, len);
    }

    void process_commands() {
        uint8_t data[64];
        int len = uart_read_bytes(UART_NUM, data, sizeof(data), 0);
        if (len <= 0) return;

        if (_rx_len + len >= (int)sizeof(_rx_buf) - 1) {
            _rx_len = 0;
        }
        memcpy(_rx_buf + _rx_len, data, len);
        _rx_len += len;
        _rx_buf[_rx_len] = '\0';

        char *p = _rx_buf;
        while (true) {
            char *nl = (char *)memchr(p, '\n', _rx_len - (p - _rx_buf));
            if (!nl) break;
            *nl = '\0';
            _process_line(p);
            p = nl + 1;
        }

        int remaining = _rx_len - (p - _rx_buf);
        if (remaining > 0 && p != _rx_buf) {
            memmove(_rx_buf, p, remaining);
        }
        _rx_len = remaining;
        _rx_buf[_rx_len] = '\0';
    }

    uint32_t brightness_for_led(uint8_t led) const {
        if (led > 2) return 0;
        return (uint32_t)led_intensity[led] * MAX_BRIGHTNESS / 255;
    }

private:
    char _rx_buf[128];
    int _rx_len = 0;

    void _process_line(const char *line) {
        if (strncmp(line, "SET_LED:", 8) != 0) return;

        char color = line[8];
        if (line[9] != ':') return;

        int value = 0;
        for (const char *p = line + 10; *p >= '0' && *p <= '9'; p++) {
            value = value * 10 + (*p - '0');
        }
        if (value < 0) value = 0;
        if (value > 255) value = 255;

        int idx = (color == 'R') ? 0 : (color == 'G') ? 1 : (color == 'B') ? 2 : -1;
        if (idx >= 0) {
            led_intensity[idx] = (uint8_t)value;
        }
    }
};

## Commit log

2026-05-03 begin layout
    [input_stage.kicad_sch, isolation.kicad_sch, output_stage.kicad_sch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]
2026-05-08 vias + logo
    [usb-instrument.kicad_pcb]
2026-05-08 smal fixes
    [usb-instrument.kicad_pcb]
2026-05-08 added production files
    [usb-instrument-B_Cu.gbr, usb-instrument-B_Mask.gbr, usb-instrument-B_Paste.gbr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]
2026-05-08 added Title & Rev
    [usb-instrument-B_Cu.gbr, usb-instrument-B_Mask.gbr, usb-instrument-B_Paste.gbr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]
2026-05-08 silkscreen fix
    [usb-instrument-B_Cu.gbr, usb-instrument-B_Mask.gbr, usb-instrument-B_Paste.gbr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]
2026-06-28 Ergänzung der LED Steuerung in der Software
2026-06-28 Added LED mA to plot
2026-06-29 updated footprints
    [bom.csv, designators.csv, input_stage.kicad_sch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]
